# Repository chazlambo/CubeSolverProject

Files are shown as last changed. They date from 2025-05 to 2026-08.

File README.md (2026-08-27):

# CubeSolver

A self-contained Rubik's Cube solving robot: six stepper-driven faces, two servo
grippers on a moving ring, eighteen color sensors, an on-board Kociemba
two-phase solver, and a 320×240 display. Scan, solve, execute — no PC involved.

Everything here is one person's design: mechanical (SolidWorks), electrical
(KiCad), and firmware (Teensy 4.1).

---

## Status

**Working:** full autonomous scan → solve → execute cycle, driven from the
panel menu: the five Modes (Scramble Solve, Idle, Demo, Step Solve, Patterns),
on-panel tuning with defaults in source and overrides in EEPROM, a hardware jog
page, live sensor diagnostics, an EEPROM fault log and lifetime stats. The
display stays live during scan and solve, the abort chord works throughout,
encoder faults are detected and handled, a scan is validated piece-by-piece
with automatic repair, and color classification carries a per-sensor
confidence.

**Known unfinished:**
- `VirtualCube::rebuildFromCubeArray()` — still labeled `UNFINISHED NEEDS
  DEBUGGING` in its header, but the body is live and the firmware now relies
  on it (Cube State and pattern completion refresh the color array through
  it). The stale part is the label, not the code; it has no rollback on
  failure, which no current caller needs.
- Color sensor board 2, sensor 2 has a **dead green channel** — it reads exactly
  `0` for all six sticker colors in every archived calibration run. The firmware
  now detects this (`ColorSensor::checkSensorHealth`) but it is a hardware fault.
- Face steppers run without an acceleration ramp (`MultiStepper` is constant
  speed by design). Left as-is deliberately — a ramp would slow the solve.

---

## Which sketch do I flash?

**`Code/Main Code/CubeSolver/CubeSolver.ino`** — that's the program.

Everything under `Code/Test Code/` is bring-up and calibration tooling. The ones
still worth keeping:

| Sketch | Purpose |
|---|---|
| `Test Code/Bench_Tune` | Headless Serial protocol for scripted tuning: moves, parameters, every encoder before/after each move. Driven by `Code/tools/bench.py` |
| `Test Code/Actuator_Test` | Serial menu for manual moves and jam-recovery testing |
| `Test Code/Test_Motor_Calibrate` | Motor encoder calibration (also Settings → Calibration → Motor Positions) |
| `Test Code/Test_Color_Calibrate` | Color calibration (also Settings → Calibration → Color Sensors) |
| `Test Code/I2C_Search` | Bus scanner — genuinely useful on a five-mux rig |
| `Test Code/Test_Menu` | Menu, wheel and panel bench test — see below |

**`Test Code/Test_Menu`** drives the same `CubeMenu` and `CubeDisplay` the
firmware does, so anything that feels wrong there feels wrong in the firmware.
It runs no scan, solve or calibration. It does move real hardware from three
places: **Load** / **Eject**, the **Actuators** page (every servo and ring
position, each face motor and both whole-cube rotations, one part at a time),
and Diagnostics → Tuning → Servos, which drives a horn to each value as you
dial it. Everything under `Screens` is drawing only.

It also carries a `Screens` submenu that draws each operation screen (scan step
rows, calibration color chips, the solve progress bar, the error look) from
canned data, so the panel can be judged and photographed in seconds instead of
by running a 40-second scan to check one label. `Input Report` is a live
readout of the wheel count and every button — the fastest way to spot a flaky
encoder or a dead button.

It runs in the simulator too, with no machine at all:

```sh
cmake -S Code/sim -B Code/sim/build-test -DSIM_SKETCH=Test_Menu
cmake --build Code/sim/build-test -j && ./Code/sim/build-test/cubesim
```

`Test Code/_Archive/` does not compile against the current tree (it includes a
`Cube.h` that no longer exists). Git history is the archive.

---

## Build

**Board:** Teensy 4.1. Not a 4.0 — the solver's lookup tables alone are 4.14 MiB,
which is 214% of a 4.0's flash, and pins 40/41 don't exist on a 4.0.

**Toolchain:** Arduino IDE + Teensyduino.

> **TODO:** record the exact Arduino IDE and Teensyduino versions you build with,
> plus CPU speed and USB type from the Tools menu.

**Sketchbook layout — this is the non-obvious step.** `Code/libraries/` is an
Arduino *sketchbook libraries* folder, and the build must compile the repo's
copy, not a stale one. Two working setups:

1. **Point the sketchbook at the repo:** set Arduino's sketchbook location to
   the `Code/` directory (File → Preferences → Sketchbook location). Then
   `#include <CubeSystem.h>` and `#include <kociemba.h>` resolve, and
   `lv_conf.h` is found automatically.
2. **Link from the default sketchbook** (what this machine actually does —
   the sketchbook stays at `Documents/Arduino` so Library Manager installs
   land in the usual place):
   - `Documents/Arduino/libraries/CubeSolver` → symlink to
     `Code/libraries/CubeSolver`
   - `Documents/Arduino/libraries/kociemba` → junction to
     `Code/libraries/kociemba`
   - `Documents/Arduino/libraries/lv_conf.h` → a one-line forwarder header
     that does `#include "../../Projects/Cube_Solver/Code/libraries/lv_conf.h"`

Either way, do **not** copy the libraries into the sketchbook — you'll edit
the repo and build a stale copy. And never place an `lv_conf.h` inside the
`lvgl` library folder itself: if lvgl's own directory ever lands on the
include path, `__has_include("lv_conf.h")` silently builds the whole project
against that copy instead of the repo's.

### Dependencies

None of these are vendored except Kociemba. Install via Library Manager unless
noted.

| Library | Source | Notes |
|---|---|---|
| AccelStepper | Library Manager / airspayce.com | GPL-2.0 |
| MultiStepper | ships inside AccelStepper | constant-speed by design |
| PWMServo | bundled with Teensyduino | Teensy-only; **not** the stock `Servo` |
| TCA9548 | RobTillaart/TCA9548 | I²C multiplexer |
| veml6040 | ThingPulse/VEML6040 | color sensors |
| RunningMedian | RobTillaart/RunningMedian | scan filtering |
| Adafruit_seesaw | Adafruit | ANO scroll-wheel breakout |
| ILI9341_T4 | vindar/ILI9341_T4 (GitHub) | Teensy-4-specific DMA driver |
| LVGL | lvgl/lvgl | **v9.x** — the code uses v9-only APIs |
| EEPROM / Wire | Teensyduino core | two I²C buses used |
| SPI | Teensyduino core | pulled in transitively by ILI9341_T4, not included directly |
| kociemba | **vendored** at `Code/libraries/kociemba/` | from vindar/kociemba |

> **TODO:** pin the versions you actually build against, especially LVGL — the
> code uses `lv_display_create` / `lv_tick_set_cb`, which are v9-only.

### Menu theme assets

The menu's look is generated, not hand-drawn. `docs/theme/` holds the design as
two HTML files, and `Code/tools/bake_theme.py` rasterizes *those same files*
through headless Chrome at the panel's native 320x240, then packs the result
into LVGL C arrays under `Code/libraries/CubeSolver/utility/`:

```sh
python3 Code/tools/bake_theme.py              # images + fonts (needs network)
python3 Code/tools/bake_theme.py --no-fonts   # images only
```

The generated files **are committed**, so a normal build needs none of this —
run it only after changing the design. It needs `google-chrome`, `python3-pil`,
and `npx` for the font conversion.

Two things about those assets are load-bearing and easy to undo by accident:

- **They live in `utility/`.** `Code/libraries/CubeSolver` has no
  `library.properties`, so the Arduino IDE treats it as a 1.0-format library and
  compiles only the library root and `utility/`. Assets moved to a prettier
  subdirectory are silently not compiled, and the sketch fails to link.
- **The recolorable masks are RGB565A8, not A8.** LVGL reads an uncompressed
  RGB565A8 straight out of flash, but copies every alpha-only image into RAM
  first. The frame band alone is 49 KB — bigger than the 32 KB pool of the
  time, and most of today's 64 KB — so as A8 it fails to allocate, and with
  `LV_USE_LOG` at 0 it fails *silently*, drawing nothing at all. This costs
  about 220 KB of flash and is worth it.

Total asset cost: **~565 KB of flash**, against the ~3.3 MB left after the
solver's own 4.14 MiB of lookup tables. RAM is unchanged.

### lv_conf.h

`Code/libraries/lv_conf.h` is **required** and its settings are not defaults.
`LV_COLOR_DEPTH 16` must match what ILI9341_T4 expects; a mismatch does not fail
to build, it renders wrong colors and looks like a hardware fault. See the
comments in that file for the load-bearing settings.

**`LV_MEM_SIZE` is 64 KB, and running out of it hangs the machine.**
`LV_USE_ASSERT_MALLOC` is 1 and LVGL's default assert handler is `while(1);`, so
an exhausted pool is not a degraded UI — it is a halt, with no message, because
`LV_USE_LOG` is 0. It started at 32 KB, which the themed menu alone came within
~1 KB of; the operation screens took the peak to ~27 KB and the firmware hung
at boot with no output at all, so it went to 48 KB. The Sensor Test chips then
took the widget set to 35 KB and tripped the boot warning below, so it went to
64 KB. Every raise was set against a measurement, not a guess.

Two things watch this now: `CubeDisplay::begin()` prints the pool usage over
Serial once every widget exists, and warns below 8 KB free; and `M` in the
desktop simulator prints it live. Check the boot line before assuming a new
screen is free.

---

## Wiring

Verified against the `TEENSY_4.1` footprint's pad-to-net mapping in
`Circuitry/KiCad/Cube Solver/Motherboard/Motherboard.kicad_pcb`.
`Code/libraries/CubeSolver/CubeHardwareConfig.cpp` is the single source of truth
in firmware.

| Pin | Signal | Pin | Signal |
|---:|---|---:|---|
| 0 / 1 | U step / dir | 18 / 19 | **I²C0** SDA / SCL |
| 2 / 3 | R step / dir | 22 / 23 | Bottom / Top servo |
| 4 / 5 | F step / dir | 24 / 25 | B step / dir |
| 6 / 7 | D step / dir | 26 | Stepper enable (all 7) |
| 8 / 9 | L step / dir | 28 / 29 | Ring step / dir |
| 10 | Display DC | 30 | Encoder mux /RESET |
| 11 / 12 | Display MOSI / MISO | 32 | Power sense |
| 13 | Display SCK (+ onboard LED) | 40 / 41 | Color LED 2 / 1 |
| 14 / 15 | Display CS / RESET | 16 / 17 | **I²C1** SCL / SDA — see note |

**I²C addresses**

| Addr | Device | Bus |
|---|---|---|
| `0x70` | TCA9548 — encoder mux (7 AS5600 behind it) | Wire |
| `0x74`–`0x75` | TCA9548 ×2 — color board 1 | Wire |
| `0x76`–`0x77` | TCA9548 ×2 — color board 2 | Wire |
| `0x36` | AS5600 magnetic encoder ×7 | Wire (behind mux) |
| `0x10` | VEML6040 ×18 | Wire (behind muxes) |
| `0x49` | Adafruit seesaw (ANO wheel) | **Wire1** |

No pin or address conflicts.

### ⚠ Known board/firmware divergence

The firmware puts the scroll wheel on **Wire1 (pins 16/17)**, but Motherboard
Rev A routes connector J17 to **Wire0 (pins 18/19)**, and Teensy pads 16/17 are
marked unconnected. Since the machine works, there must be a bodge wire.

> **TODO:** confirm the bodge and either roll it into a Rev B or note it on the
> board. Right now this exists only in the hardware and in your head.

- **The color scanner is mounted rotated 90° from its original layout.** It
  was turned in CAD to make the assembly fit, which changed which faces each
  scan pass reads — from `[L,B] [U,F] [D,R]` to
  `[Back,Right] [Left,Down] [Up,Front]` — and **no firmware changed**, because
  `scanCube()` identifies each face from its own centre color rather than
  assuming which one it is looking at. What the design does rely on is the two
  sensors' position *relative to each other*, and rotating the whole assembly
  preserves that. Moving one sensor relative to the other would not, and would
  break `left1`/`left2` in `scanCube()`.

  The only thing tracking the physical order is `kScanPassFaces` in
  `CubeOpShape.cpp`, which fills the panel's face row during a scan. Rotate the
  scanner again and that table is the one thing to update.

Two other things worth knowing:
- **Pin 10 must be the display DC.** ILI9341_T4 drives DC through the SPI
  peripheral's chip-select logic during DMA, so it has to be a hardware CS pin —
  on Teensy 4.1 SPI0 that's 10, 36 or 37. A plain GPIO fails confusingly.
- Pins 24/25 are Teensy's `Wire2`, consumed by the B stepper. There is **no third
  I²C bus available** without moving that motor.

---

## First run

Order matters — the solver needs both calibrations, and color calibration needs
motors that already home correctly.

### 1. Motor encoder calibration

Menu → **Settings → Calibration → Motor Positions**, or flash
`Test Code/Test_Motor_Calibrate`.

Records four encoder positions per motor, one per quarter turn, into EEPROM.

> **TODO:** describe the physical setup — how the fingers should be positioned
> relative to the cube before starting, what a good result looks like, and when
> this needs redoing after a mechanical change.

### 2. Color calibration

Menu → **Settings → Calibration → Color Sensors**, or flash
`Test Code/Test_Color_Calibrate`.

Needs a **solved** cube. Steps through orientations recording a reference RGBW
per color per sensor, plus an "empty chamber" reference.

The firmware now derives a per-sensor decision threshold from this data
(`ColorSensor::computeSeparations`) rather than using one global tolerance, so a
bad calibration degrades classification measurably. Check the health report.

> **TODO:** describe ambient lighting conditions, whether the lid should be on,
> and how to tell a good calibration from a marginal one.

### 3. Servo endpoints

Menu → **Settings → Calibration → Servo Positions**. Rows preview live as the
wheel turns, behind a red confirm; values persist in the tuning EEPROM block.

The compiled defaults live in the shared parameter table
(`Code/libraries/CubeSolver/CubeTuneTable.cpp`), not in
`CubeHardwareConfig.cpp` — the `topExtPos` / `botExtPos` globals there are read
once at servo construction and then overridden at boot by the table, so editing
them no longer changes the machine.

> **TODO:** record how the defaults were determined and how to retune after
> changing a servo horn or linkage.

---

## Operating

1. Power on. The machine homes its motors if calibrated.
2. Turn the wheel to **Load & Scan Cube**, press SELECT.
3. Insert a scrambled cube, press SELECT. It scans (~25–40 s) and the main
   menu becomes **Cube Ready**.
4. Select **Solve**, press SELECT. It computes and reports the move count.
5. Press SELECT to execute (LEFT cancels and leaves the cube as it is).

**Abort:** hold SELECT and LEFT together for 1.5 s during a scan or solve. The
machine stops at the next mechanically safe point, releases the cube, and
returns to the menu.

**On any error that can leave the machine holding the cube, it is released
automatically** — the solve paths and the abort paths all route through
`safeStop()`. Scan-time color and build errors do not, because at those points
the ring and both servos are already retracted.

### Error codes

| Range | Meaning |
|---|---|
| Scan 1–3 | A sensor could not identify a face, or two faces read the same |
| Scan 1X/2X | Sensor 1/2's face was rejected when set on the virtual cube |
| Scan 3X | Could not determine orientation |
| Scan 41 | Fewer than six distinct faces set — a duplicate-centre misread |
| Scan 42-47 | Wrong number of some color (not nine of each) |
| Scan 5X | Could not build the cube array |
| Scan 60 | Physically impossible cube, auto-repair failed → rescan |
| Scan 70 | Aborted by user |
| Scan 80 / 81 | Reorientation move ROTX / ROTZ failed (encoder fault) |
| Scan 90 | A color sensor board failed to initialise at boot |
| Scan 91 | Motors failed to home before the first clamp (jam / encoder fault) |
| Cal 82 | A calibration reorientation move failed |
| Solve 11 | Cube not scanned yet |
| Solve 12 | No solution — illegal cube or solver timeout |
| Solve 13 | Centres not canonical → **orientation** was misread |
| Solve 14 | Impossible piece → a **color** was misread → rescan |
| Solve 15 | Solution longer than the move buffer |
| Exec 105 / 125 | Aborted by the user (between moves / inside a move) |
| Exec 1XX | A move failed; cube released and virtual state invalidated |
| Move 3 / 21 / 22 / 24 / 25 | Raw move (Modes, jog): invalid token / motors not calibrated / jam or align timeout / encoder unreadable / aborted |
| Move 1X | Virtual move failed — rescan |
| Cal 8 | Color calibration failed to save — machine is **not** calibrated |
| Cal 9 | Color calibration aborted; EEPROM left untouched |

The raw-move codes appear on the panel when a scramble, idle turn, pattern
fold or jogged move fails, and in the Fault Log under the Mode and Jog
sources.

Code 14 and 60 both mean "the cube I think I have cannot exist" — the fix is a
rescan, not a retry.

**Code 13 is effectively unreachable, by design.** `buildCubeArray()` relabels
colors through the reported orientation, so the centres come out canonical
whatever that orientation was. A *misread* orientation therefore produces a
different but internally consistent cube that is legal, piece-valid and
solvable — the machine would execute ~20 moves in the wrong frame with no error
at any layer. The centre check is kept as cheap insurance against a corrupted
`cubeArray`; detecting an orientation misread needs a cross-check against
something outside the cube model and is **not currently implemented**.

---

## Repo layout

```
3D Models/      SolidWorks parts and assemblies, plus print-ready STLs
Circuitry/      KiCad projects: Motherboard, Motor Breakout, Color Sensor
Code/
  Main Code/CubeSolver/   <- THE PROGRAM
  Test Code/              bring-up and calibration sketches
  libraries/
    lv_conf.h             required LVGL config (see above)
    CubeSolver/           the machine's own code
    kociemba/             vendored solver (from vindar/kociemba)
```

`.gitignore` excludes regenerable KiCad output (auto-backup zips, footprint
caches, per-user project state) and SolidWorks lock files. `.gitattributes`
marks binary CAD/fab formats `-text` so git's heuristic can't CRLF-mangle them.

---

## Notes for future-you

- **The alignment step sign lives in one place.** `CubeSystem::kAlignStepSign`.
  Both closed-loop routines use `encError()`; if alignment ever drives away from
  target, flip that constant and nothing else.
- **Encoder reads can fail.** `MotorEncoder::scanChecked()` returns negative on
  I²C failure and every control path treats that as a fault, not a position.
  Never go back to raw `scan()` in a control loop.
- **`pumpDelay()` instead of `delay()`** anywhere that waits more than a few ms,
  so the display and abort keep working.
- **The panel is driven synchronously, on purpose.** `CUBE_DISPLAY_ASYNC_DMA`
  in `CubeDisplay.h` is 0: every LVGL flush is written straight to the glass
  and returns when it is on the wire. The driver's async DMA/differential mode
  (mode 1) is faster, but on this board it left the glass holding the previous
  frame in large chunks, or coloured snow, while the driver believed the new
  one had been sent — and because that mode only ever re-sends pixels it thinks
  changed, the damage stayed until something drew over it. The header comment
  has the history. `cubeDisplay.repaintAll()` re-sends every pixel; the sketch
  calls it at the end of boot and on every return to the menu. In mode 1 never
  use `tft->update(internal_fb)` for that: handed its own buffer the driver
  rotates it onto itself.
- **A white panel heals itself now.** On the same marginal wire, a corrupted
  byte during a heavy flush can land in the panel's command slot — `RAMWR`
  (0x2C) and `CASET` (0x2A) are each one flipped bit from `DISPOFF` (0x28) —
  and a panel that latches `DISPOFF`/`SLPIN`/`SWRESET` shows solid white,
  which no amount of pixel drawing repairs. `CubeDisplay::panelHealthTick()`
  (run from every `update()`) re-sends `DISPON`+`SLPOUT` each second and
  re-runs the full init when the self-diagnostic register reads wrong, so a
  white-out lasts about a second instead of until power-cycle. It prints
  `Display: panel lost its init (recovery #N)` on Serial; that count climbing
  while scrolling is the wire talking.
- Solve times: Kociemba runs from flash. `set_memory()` would be ~4× faster but
  the 479 KiB buffer doesn't fit alongside the display's ~200 KB of RAM2.

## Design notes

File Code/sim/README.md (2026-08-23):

# CubeSolver desktop menu simulator

Runs the **real firmware** on a PC, with the ILI9341 panel and the seesaw wheel
replaced by SDL. Layout, fonts, text wrapping, navigation and LVGL memory
behaviour are all faithful, because they are produced by the same code that
ships — there is no second copy of the menu to drift out of step.

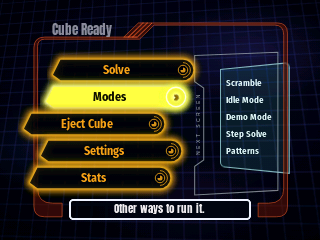
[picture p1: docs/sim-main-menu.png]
what it looks like


## Build and run

```sh
cmake -S Code/sim -B Code/sim/build
cmake --build Code/sim/build -j
./Code/sim/build/cubesim            # --scale 1..8, default 3
```

By default this builds the firmware sketch. `-DSIM_SKETCH=Test_Menu` builds
`Code/Test Code/Test_Menu` instead — the bench sketch for the wheel, the buttons
and the panel, including canned demos of every operation screen. Use a separate
build directory so the two do not fight over one CMake cache:

```sh
cmake -S Code/sim -B Code/sim/build-test -DSIM_SKETCH=Test_Menu
cmake --build Code/sim/build-test -j && ./Code/sim/build-test/cubesim
```

Needs `cmake`, a C++17 compiler, and network access on the first configure:
LVGL is fetched, not vendored, and so is SDL2 unless pkg-config finds a system
copy (`libsdl2-dev` on Debian/Ubuntu makes the configure faster, nothing more).

```sh
sudo apt install cmake build-essential libsdl2-dev   # optional on Linux
```

## Controls

**Machine controls** — these are the real machine's inputs:

| Key | Acts as |
|---|---|
| up / down arrow, mouse wheel | turning the wheel |
| `W` / `S` | the discrete UP / DOWN buttons |
| `Return`, `Space` | SELECT |
| left arrow, `Backspace` | LEFT (back) |
| right arrow | RIGHT (enters, same as the firmware) |
| `Return` + left arrow, held 1.5 s | abort the running operation |

**Simulator controls** — these do not exist on the machine:

| Key | Effect |
|---|---|
| `F` | arm a fault; the next operation fails |
| `C` | toggle whether a cube is loaded and scanned (flips the main menu) |
| `K` | toggle the calibration flags |
| `M` | print the LVGL heap report to the console |
| `P` | screenshot to `sim-shot-NN.bmp` |
| `Esc`, close window | quit |

## What is real and what is not

**Real, compiled unmodified from `Code/libraries/CubeSolver`:** the sketch
itself (`CubeSolver.ino`), `CubeMenu`, `CubeDisplay`, `RotaryEncoder`,
`CubePump`, `CubeServo`, `CubeMotors`, `ColorSensor`, `MotorEncoder`,
`VirtualCube`, the baked theme assets in `utility/`, and the repo's own
`lv_conf.h` — including its `LV_MEM_SIZE`, so LVGL pool pressure shows up
here rather than on the bench.

That last point is not theoretical. The menu theme's frame band was originally
baked as an A8 mask, which LVGL copies into RAM rather than reading from flash;
at 49 KB it did not fit the pool, and because `LV_USE_LOG` is 0 it failed by
silently drawing nothing. `M` prints the heap so that class of bug is visible
here instead of on the bench. The pool is 64 KB (`LV_MEM_SIZE`);
`CubeDisplay::begin()` prints its usage at boot and warns below 8 KB free, and
note that exhausting it halts the firmware in a `while(1)` rather than
degrading — which is exactly how it presents: a window that never draws.

**Real behaviour worth knowing about:**

- Start-up takes about ten seconds. Both servos sweep at 15 ms/degree through
  the real `CubeServo` code, exactly as the machine does. The first run is the
  slowest, because with no `sim-eeprom.bin` the servo state is unknown and
  `begin()` assumes worst-case travel.
- The abort chord is the firmware's own `pumpTick()`, copied rather than faked.
  Hold `Return` + left arrow during a scan and watch it unwind.
- `sim-eeprom.bin` persists calibration flags and servo positions between runs.
  Delete it to simulate a virgin board.

**Simulated:** `CubeSystemSim.cpp` replaces `CubeSystem.cpp` — the *only*
firmware file the simulator swaps out. Scan, solve, execute and calibration
report progress and consume a plausible amount of time (roughly a fifth of the
machine's, so menu work does not mean waiting out a 40-second scan), and can be
made to fail with `F`.

**Not simulated:** SPI refresh rate and tearing on the real panel, I2C timing
and bus contention, seesaw debounce, and actual cube solving — `kociemba` is
stubbed. The virtual cube's ready/not-ready state *is* real, which is what
drives the pre-scan vs post-scan main menu.

## Driving it from a script

Screenshots and regression walkthroughs work with `xdotool`, with three traps.
All three fail the same way — silently. Keys go nowhere and the run finishes
looking successful, so a walkthrough that captures no screenshots is far more
likely to be a driver problem than a firmware one. Check the shot count first.

```sh
./Code/sim/build/cubesim --scale 2 &
sleep 14                        # let the servo sweeps finish

# Trap 1: SDL creates more than one X window and only one of them takes
# keyboard focus. Do not guess which — try each and keep the one that sticks.
for W in $(xdotool search --name "CubeSolver menu simulator"); do
    xdotool windowactivate --sync "$W" 2>/dev/null; sleep 0.3
    [ "$(xdotool getwindowfocus)" = "$W" ] && WID=$W
done

# Trap 2: buttons are LEVEL-sampled every 25 ms by the firmware, so a press must
# be HELD. `xdotool key Return` is far too brief and is silently dropped.
#
# Trap 3: focus DRIFTS. Focusing once at the start is not enough — a few keys in,
# focus lands on some other window and the rest of the walkthrough types into it.
# Re-assert focus before every key; it costs a few ms and removes the whole class
# of "it worked yesterday" failures.
act()  { xdotool windowactivate --sync "$WID" 2>/dev/null; }
tap()  { act; xdotool key "$1"; sleep 0.7; }
hold() { act; xdotool keydown "$1"; sleep 0.16; xdotool keyup "$1"; sleep 1.0; }

hold Return                     # SELECT
tap p                           # screenshot (the wheel/encoder path IS
                                # event-driven, so brief keys work for it)
```

## Going further (Tier 2)

Swapping `CubeSystemSim.cpp` for the real `CubeSystem.cpp` would give genuine
scan → solve → execute against a real virtual cube, enough to develop Scramble,
Idle, Demo and Patterns entirely on a PC. Two things stand in the way:

1. `homeMotors()` and `alignMotorsInternal()` poll the AS5600 encoders in a
   loop, so `MotorEncoder`/`AccelStepper` need to model a motor converging on
   its target rather than returning a constant.
2. The real kociemba solver has to be added to the build. It is portable C++ and
   compiles on a host unmodified — `shim/kociemba.h` deliberately keeps the same
   signature as `Code/libraries/kociemba/kociemba.h` so this is a build-list
   change, not a code change.

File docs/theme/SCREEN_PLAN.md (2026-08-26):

# Screen plan — what the rest of the machine needs to look like

Every menu item that once landed on "Not implemented yet", designed before it
got written. As of firmware 1.0.0 every screen here is **BUILT**, machine side
included — the per-screen statuses say so. The point was never to lock anything
down; it is so that the tenth screen looks like it belongs with the first, and
so the shared pieces get built once instead of five slightly different times.

Read `UI_DESIGN.md` first — it covers the palette, the limits and the traps.
This file was about screens that did not exist yet; it stays as the record of
why each one looks the way it does.

---

## The rule everything here follows

**Bar art means "you can select this."**

The glowing bar with the socket and the cursor orb is the menu's vocabulary for
a choice. It was briefly reused to show scan progress, and the result read as a
screen full of buttons that did nothing — the shape promised an interaction that
was not there.

So: a bar is a thing you can pick. Status is chips, a progress bar, a table, or
text. Never a bar. When something is genuinely a list of choices — Patterns,
Parameters — bars are exactly right and should be used.

Second rule, and it has been rewritten since most of this file was: **the
frame color is where you are.** A branch of the menu tree is one color from the
row that opens it all the way out through the operation screens it leads to —
blue for the main line of work, red for Modes, green for Eject, yellow for the
whole Settings subtree, purple for Stats. A new screen does not pick a color;
it inherits its branch's.

It used to mean machine state — blue scanning, green solving, violet
calibrating — and several sections below still describe screens in those terms,
noted where they do. The two schemes fought over one band, because a menu
already recolors by selection, and wayfinding won. Only `Error` kept its old
meaning: **red, always, whatever branch it happened in.** `UI_DESIGN.md` §2 has
the full rule and the one other exception (Idle Mode's decorative cycle).

### The Settings subtree

Restructured with the color change, since one branch of one color also wants to
be one branch of one shape:

```
   Settings
     Diagnostics     read the machine    Hardware Test, Sensor Test,
                                         Cube State, Fault Log
     Calibration     teach the machine   Status, Color Sensors,
                                         Motor Positions, Servo Positions
     Parameters      change the machine  the six tuning sections
     About
```

Diagnostics above Calibration because looking comes before altering, and
Parameters promoted out of Diagnostics to sit beside Calibration because it
WRITES — filing it under a menu named for reading was always a lie about it.
Every screen under Settings is yellow. That does cost the local distinction
Settings used to draw between Diagnostics (purple) and Calibration (violet);
the title line still says which, and one branch of one color is the trade.

---

## Vocabulary we have

| Piece | Call | Says |
|---|---|---|
| Frame color | `opScreen(kind, …)` then `setOpTheme()` | which branch you are in |
| Title | `showOperation(…, title, …)` | where you are |
| Headline / sub-line | `showOperation(…, headline)` / `setStatus()` | what it is doing now |
| Status table | `setOpLines()`, `"Label\tValue"` | facts, up to 7 rows (`kOpLines`) |
| Face row | `setOpFaces()` | the six faces, filled with the color actually read |
| Chip rows | `setOpChips()` | a set being collected, two rows |
| Progress bar | `setOpProgress()` | how far through a countable job |
| Dial | `setOpDial()` | a setting you are steering, and where it sits in its range |
| Hint box | `showOperation(…, hint)` | what button to press |
| Preview pane | menu only | what is behind this item |

## Vocabulary added while building

Where each of the later pieces lives:

| Piece | Call | Built for |
|---|---|---|
| Cube net | `setOpCubeNet()` | Cube State, scan review, Patterns, the two Solve thinking screens |
| Chip row | `setOpChipRow()` / `setOpFaces()` | scan faces, calibration, the jog strip |
| Move ribbon | `setOpRibbon()` | Step Solve |
| Row status marks | `setOpLines(..., marks)` | the jog cursor; Sensor Test uses it too |
| Frame recolor | `setOpTheme()` | the branch color, and Idle Mode's cycle |

Two more pieces came with the machine side:

1. **Scrolling status list**, for Fault Log. More than a page of rows
   (`kOpLines`, seven) with a position readout in the hint bar rather than a
   scrollbar the theme has no art for.
2. **Value editor**, for Parameters and Servo Positions. The Actuators
   page's enter-pick-send on a gripper proved the interaction; the editor adds
   a NUMBER rather than three named positions, with the step size a column of
   the shared parameter table.

### On the cube net — built, and how

`setOpCubeNet(facelets)` takes 54 color letters in the standard order and draws
the unfolded cross. `VirtualCube::getColorArray()` returns exactly that.

It is **not** LVGL primitives and **not** `lv_canvas`. It writes RGB565A8 into a
plain static buffer and hands that to an `lv_image`. Three reasons, all of which
apply to the next thing like it:

- 54 stickers as objects would be most of the pool for one screen.
- The buffer (39 KB at 10 px stickers) is several times the whole LVGL pool, so
  it must be a static array, not an `LV_MEM` allocation. Teensy RAM has room;
  the pool does not.
- LVGL reads an uncompressed variable-source image **straight out of the buffer
  without caching it** (`use_directly` in `lv_bin_decoder`). So redrawing is
  "rewrite the bytes, call `lv_obj_invalidate()`" — no reallocation, no cache
  invalidation dance.

Gaps between stickers are alpha 0, so the net sits on the themed backdrop rather
than on a grey slab. A facelet that is not a known color is drawn as a hollow
outline, so a bad sticker reads as wrong rather than as missing.

**Still missing:** per-face rotation for a *raw* scan. Cube State falls back to
showing the last scan when nothing was built, but each face is laid out as its
sensor saw it — `setOrientation()` resolves that only when the cube is built. A
stray sticker is visible; where it sits within its face may be turned. The
screen says "last scan, not built" rather than pretending otherwise.

```
        ┌──┬──┬──┐
        │  U     │            standard unfolded cross:
        ├──┼──┼──┼──┬──┬──┐   4 faces wide, 3 tall
        │  L  │  F  │  R  │  B     at 10 px/sticker -> 132 x 99
        ├──┼──┼──┼──┴──┴──┘   centred, with the sub-line below it
        │  D     │
        └──┴──┴──┘
```

---

## Screen by screen

Sketches are the ~240x150 content area inside the frame. The title sits top-left
and the hint box along the bottom on every one of them.

### Solve, the thinking half — top level — **BUILT**

The two screens between pressing Solve and the machine moving. Both are the
same picture: the net of the cube *as it stands*, drawn by `setOpCubeNet()`
from `VirtualCube::getColorArray()`. One function draws both — `drawSolveNet()`
in the sketch — because they ask the operator the same question, "is this the
cube you loaded", and only the line under the net changes.

```
        [ the unfolded net, y=60..150 ]
           Finding solution...                <- sub-line, under the net
                                              <- no hint: nothing is polled
```
```
        [ the same net ]
         Solution found in 21 moves           <- Cube.solutionLength, not a recount
      SELECT to solve, LEFT to cancel         <- hint box
```

**No headline on either**, and that is structural rather than taste: the net
occupies y=60..150 and `showOperation()` puts the headline at 58, so a screen
carrying both draws one through the other. `setOpCubeNet()` moves the sub-line
below the net for exactly this reason.

The first screen has **no hint** because `solveVirtual()` blocks *without*
pumping — nothing is polled while it is up, so an abort line would advertise a
gesture the machine cannot hear.

The first screen is painted by the Solve action but *flushed* by the `Solving`
state, which pumps one refresh period (`pumpDelay(40)`) before the search
blocks. A single `displayUpdate()` only marks widgets dirty; LVGL repaints when
its 33 ms timer comes due, and without the pump the panel stayed on the menu
for the whole compute — Solve read as a press that had not registered.

The second is `AppState::SolveConfirm`, and its whole value is that nothing has
started yet: no gripper driven, no solve timer, no stats touched. LEFT is
therefore free — it returns to the menu leaving the cube exactly as it stood
(clamped, in the usual case, which is where the scan and the previous solve
leave it) and leaving no half-started solve behind. SELECT falls through to
`Loading`.

**Only say the machine is clamping when it is.** `Loading` clamps *only* if
`cubeIsClamped()` says it is not already, and the "Clamping the cube" screen now
lives inside that branch. It used to be painted unconditionally on the way in
from `Solving`, which claimed a clamp on the common path where nothing moved.

The whole run — both of these, the clamp if there is one, the moves, the display
spin — wears the Solve row's **blue**, by the ordinary `s_opTheme` mechanism
(§ "The rule everything here follows"). Nothing on the path names a colour; the
`Op::Done` on the display spin is a label only, since `opScreen()` repaints the
branch colour over the kind's fallback. A failure leaves through `fail()` and is
red, as everywhere.

### Solve, the display spin — top level — **BUILT**

How a plain Solve ends. Not a straight release any more: the machine lets go of
the ring and the top servo, keeps the cube up on the bottom gripper, and turns
it slowly on the spot — one revolution about every eight seconds — while the
result stands on the screen. With nothing else engaged the D motor turns the
WHOLE cube rather than a face, which is why the model is never told about it.

```
                Solved!                     <- headline
           21 moves in 4.62 s               <- sub-line, the shared formatter
      SELECT clamps the cube and finishes   <- hint box
```

Reuses everything; needed nothing new. The interaction is the one novel part:
SELECT (or LEFT) finishes the revolution so the cube is square, clamps it again
bottom -> ring -> top, and returns to the menu — which leaves the machine
holding the cube, so the next Solve skips its own clamp.

**Modes do not end here.** They still finish through `Unloading`: Demo loops and
would stall on a screen that waits for a press, and Step Solve is already
human-paced. Making it universal is a one-line change, recorded in the sketch
above `drawSolveDisplay()`.

Rehearsed in `Test_Menu` as `Screens > Operations > Solve Result` — the
"Solved!" screen the Scramble Solve demo already draws, minus the ribbon and
bar, plus a hint. The spin itself is the part no bench sketch can show, so the
demo is the still frame only.

### Eject — top level — **BUILT**

Was a screen that asked for a press: "take the cube out, then press SELECT". It
watches now. The machine releases the ring and the top servo, lifts the cube on
the bottom gripper — `unloadCubeKeepBottom()` then `botServoEject()`, straight
there, no dip into the bay first — and then leaves both color boards illuminated
and sweeps all eighteen sensors five times a second.

```
             Take the cube out              <- headline
     SELECT if the machine does not notice  <- hint box
```

The hint is the whole design of the screen. The cube can just be taken, so the
headline says only that; the button is named as a backstop, not as a step,
because promising a press the operator does not need is how the old screen was
wrong.

Detection is **tare, pick witnesses, watch for the fall**. Once the LEDs have
warmed, three `presenceSweep()`s of every sensor on both boards are averaged
into a per-sensor baseline — taken while the cube is definitely still there.
The sensors reading at least 50% of the brightest baseline are the *witnesses*:
at the eject height the cube's lowest row sits a couple of millimetres from the
top row of each board and bounces the LED straight back, while everything else
looks at the bay, so brightness alone sorts out which sensors can see the cube.
The cube is gone when more than half the witnesses have fallen to 40% of their
own baselines for four consecutive sweeps. No absolute brightness anywhere —
ambient light, LED output and sticker color all vary, and each baseline is
measured against the very sticker that is about to leave. A negative read is
an I2C fault and is never removal. A *fall* rather than "any change", because
a hand reaching in is also a change — it reflects the LED into the bay-facing
sensors a second before the cube leaves — but it cannot get between a sticker
and the sensor it sits 2 mm from. The debounce is there because a cube loosely
held can clear its witnesses while still resting on the platform.

Every ending — detected, SELECT, the 120 s give-up timeout, the abort chord —
goes through one `ejectFinish()`: LEDs off, bottom servo down, back to the
menu, where the root list reverting to its pre-scan form is the confirmation.
No "Cube ejected" acknowledgement screen, because that was the press being
removed.

**No sensor is chosen by hand.** The first version watched one sensor — first
the centre, then the bottom-middle — and stood through its timeout, because
which of the nine is physically uppermost is not knowable from this tree: the
`{UL, UM, UR, ...}` names in `CubeHardwareConfig.cpp` predate the 90° scanner
rotation the README describes. Sweeping all eighteen and letting the tare say
which ones see the cube removes the guess. The tare and the verdict go to
Serial (`Eject tare ...`, `Eject: cube gone ...`), which is where the 50%/40%
thresholds get confirmed on the bench; the timeout exists so a machine whose
sensors cannot see the cube at this height costs two minutes rather than forever.

Rehearsed in `Test_Menu` as `Screens > Operations > Eject Prompt` — the
prompt only. `Test_Menu`'s own root `Eject Cube` is an actuator exercise, not a
screen demo, and the watch itself needs the real color boards, so neither
rehearses the detection.

### Scramble Solve — Modes — **BUILT**

Two phases — scrambling, then solving — and the headline, sub-line and bar all
say which. **They no longer recolor the frame.** The frame is red throughout,
because red is Scramble Solve's place in the tree, and the frame answers "where
am I" rather than "which half is this". The as-built plan below was written
under the old rule and the color half of it is superseded.

```
              Scrambling                    <- headline, per phase
             Move 7/25   R'                 <- sub-line
        ▓▓▓▓▓▓▓▓▓░░░░░░░░░░░░░              <- progress bar
```

Reuses everything. Needed nothing new. Built first — it was the cheapest of
the Modes, and the phase-color idea it proved is the one that later lost to
wayfinding.

### Idle Mode — Modes — **BUILT**

The machine turning to look alive between visitors: a random quarter turn every
so often, waiting for someone to walk past.

```
              R'                     <- the last move, large
        Moves      12
        Every      10 s
              wheel sets the gap - SELECT solves
```

Three controls share one screen and none needs a mode of its own, because
there is no cursor here to move and nothing to enter:

| | |
|---|---|
| wheel | how long between moves, 1-60 s |
| SELECT | stop idling and solve it |
| LEFT | back, as everywhere |

The gap **clamps** rather than wrapping. A cursor may wrap because every item is
equivalent; rolling a one-second gap round to a minute because the wheel went
one detent too far is a different kind of surprise. Changing it also re-times
the pending move from now — shortening the gap and then waiting out the old one
reads as the setting not working.

The frame color advances with each MOVE rather than on a timer of its own. This
is the one sanctioned exception to frame-color-as-wayfinding: everywhere else
the band says which branch you are standing in, and here it cycles all six on
purpose. Tying it to the moves is what keeps it honest — a color change means
something happened, so the machine reads as alive from further away than the
move counter can be read. Idle Mode's other screens (the clamp, and the solve
SELECT hands off to) wear the mode's own yellow.

Idling **disorders the cube** — Step Solve must not then scramble a cube that
is already scrambled. The firmware derives that from the cube model itself
(`cubeIsSolved()`) rather than a flag, so the two cannot disagree.

### Demo Mode — Modes — **BUILT**

Scramble, solve, repeat, unattended. Both halves already existed — the phase
handling from Scramble Solve, the ribbon from Step Solve — so it is a loop
around them plus a run counter.

Four phases, because the machine has four. The colors this table used to name
are gone: Demo Mode is **blue** end to end, its row's color in the Modes menu.
A run scrambles and solves and scrambles again every few seconds, and
recoloring the halves would have said the machine kept changing job.

```
   Scrambling                     30 moves, ribbon + bar
   Computing the                  the handover: no ribbon, no bar
     solution
   Solving                        21 moves, ribbon + bar
   Solved!                        the result, briefly
```

The pause to compute is not padding. The real machine has to work out a solution
before it can run one, and a demo that jumped from the last scramble move
straight to the first solve move would be showing something the machine never
does. The handover happens THERE rather than at the first solve move, because
that is the moment it stops scrambling — and the ribbon and bar go, because
neither has anything true to say about a search that has not finished.

It shows the MOVES because the whole point of leaving it running is that it
should be worth watching. The scramble is its own list — thirty moves, no two in
a row on the same face, which is what a real scramble looks like and the reason
it reads differently from a solution.

### Step Solve — Modes — **BUILT**

Scrambles thirty moves first, then steps — but only if the cube is not already
scrambled. Idle Mode and a previous run both leave it disordered, and thirty
moves spent re-scrambling a scrambled cube would be a lie about what the machine
does.

Three phases: scrambling with the scramble ribbon running, computing, then the
step-through. **Purple** throughout — Step Solve's color in the Modes menu — and
not the red/yellow/green progression this originally specified; see the second
rule above. The compute phase must still CLEAR the ribbon and the progress bar:
left up, a finished ribbon and a full bar sit under the word "Solving" and read
as a solve that finished before it started. Both hide on a null/zero argument.

One move per press. This is what the **move ribbon** is for.

```
             Move 7 of 21

     R   U2   F'   ⟨ L ⟩   D   B2   R'      <- current in cursor yellow,
                                               past dimmed, future grey
```

Deliberately **plain text tokens, no boxes** — boxed tokens would drift back
toward looking like buttons. Color alone carries the cursor.

`setOpRibbon(moves, count, current)` centres the window on the current move and
shows about seven. Hint: "SELECT for next move".

### Patterns — Modes — **BUILT**

A *menu*, so bars are correct here — and the preview pane is the obvious home
for a small cube net of what each pattern produces. That is the pane doing
exactly what it was designed for.

```
   ╭─ Checkerboard ─╮        ┌──────┐
   ╰────────────────╯        │ net  │   <- preview pane, ~66x96,
   ╭─ Cube in Cube ─╮        │      │      net at 5 px/sticker
   ╰────────────────╯        └──────┘
   ...
```

**Prototyped** in `Test_Menu` (Screens > Patterns). `MenuItem::previewNet` holds
54 facelets and `setPreview()` draws them in the pane at 3 px stickers, sharing
one `drawNet()` with the full-size version so the two cannot disagree about what
a cube looks like.

Nine patterns now, split across two screens because five rows is the limit:
Checkerboard, Cube in Cube, Six Spot and Superflip plus a **More Patterns**
row leading to Cube^3, Anaconda, Python, Tetris and Twister (sequences from
ruwix.com). Each screen's rows index the shared `kPattern*` tables from its
own base — table order is screen order, first screen then second.

The states are computed by applying each well-known sequence to a solved
cube and checked for nine of every color — a preview that is not a real cube
would hide exactly the bugs this screen is for.

The machine side — running the moves — is built now too. The fold refuses a
cube that is not solved, because the preview is a promise about the result.

### Cube State — Diagnostics — **BUILT**

The net plus a color count. Nine of each is the cheapest check that the stored
state is a cube at all, and unlike "invalid" it says *which* color was misread.

It doubles as the **scan review**: with nothing built but a scan recorded, it
shows the raw readings instead of an empty screen — which is the case where
somebody most wants to look. See the caveat above.

**And it turns.** With a model built, the wheel points at a face and UP/DOWN
turn it, with the net redrawing after each move. The turn is applied to the
**model only** — no motor, no servo — which is the opposite half of the trade
`jogTurn()` makes on the Hardware Test page: that page moves the machine and
therefore cannot keep the model, and this one keeps the model and therefore
must not move the machine. Same desync, opposite ends.

The screen says so in capitals under the net, next to the `< U >` selector,
because the whole risk of the page is an operator believing the machine just
moved.

A model left turned would desync just as badly the other way — Solve would run
against a state the machine is not holding — so the page does not leave it
turned. Every move goes on a 60-entry trail (a turn that undoes the previous
one pops instead of pushing, so forward-and-back costs no depth) and **every
exit replays it backwards inverted**. A scan survives a visit here.

The raw-scan form stays read-only: `VirtualCube::executeMove()` refuses a cube
that is not ready, and the per-face rotation is unresolved anyway, so a turn
would shuffle stickers inside a frame that does not mean anything yet.

Still worth adding: mark the low-confidence stickers. `scanAlt` and `scanConf`
already record the runner-up color and the confidence for every sticker, so the
data is there — a hollow or outlined sticker for "the classifier was unsure
about this one" would turn this from *what it read* into *what to distrust*.

### Fault Log — Diagnostics — **BUILT**

A list nobody selects from, so status rows rather than bars.

```
        12:04   Solve stopped      122
        11:58   Scan failed         60
        11:51   Aborted             25
        ...
```

Seven rows at a time — the whole of `kOpLines` — wheel scrolls, and the
position goes in the hint box — "8-14 of 24" — rather than inventing a
scrollbar the theme has no art for.

### Hardware Test — Diagnostics — **BUILT**

**Not a self-test.** It is manual control: drive each actuator to each position,
by hand, one at a time. The panel version of `Test Code/Actuator_Test`, which is
a numbered list over Serial. It is where you go to answer "does that servo
actually reach retract", and where you drive one part at a time to show the
machine off.

It started as a menu of every action, and that was wrong: nine entries across
three screens for the grippers alone, twelve more for the faces, all clicked
through one at a time — when what you want is to pick a thing and nudge it while
you watch it move.

So the two busy pages are **direct manipulation**, not menus. They can be,
because the wheel and the UP/DOWN BUTTONS are separate inputs on this encoder.
A menu collapses them into one meaning; a jog page gives them two:

```
    wheel        choose which part
    UP / DOWN    move that part
    LEFT         back, exactly as everywhere else
```

**One page, no submenu at all.** Twelve things on one wheel — three grippers,
the cube button, six face motors, two whole-cube rotations — and it wraps.

```
   Top servo                  < Extend >     <- entered: the candidate
   Bottom servo                       ?
   Ring                          Middle
   Eject cube                                <- named for what it will DO
   [U] [R] [F] [D] [L] [B] [RotX] [RotZ]
```

Load and eject are ONE row, because the cube is either in the machine or it is
not. It is named for what pressing it will do, so there is nothing to read twice.

Keeping them together is not only tidiness. **A face motor cannot turn until the
grippers are clear**, so seeing where the grippers are WHILE jogging a face is
the difference between a considered press and a jam.

**Two levels everywhere: scroll to a thing, SELECT to enter it, LEFT to leave.**
Entering something used to turn the frame yellow. The frame is Settings' yellow
throughout now — it says where you are, not what is armed — so the hint line and
the row mark carry that instead. Both already changed with the state.

What the wheel then does depends on what you entered, and that difference is the
whole design:

- A **gripper is a position**. The wheel picks one, SELECT sends it, and nothing
  moves until you say so.
- A **motor is a thing you turn**. Once you have taken the wheel, every detent
  IS a turn — which is what a jog wheel should feel like, and it means watching
  a motor through several turns costs no button presses at all.

The cursor is a **marked row**, not a bar:
they are a readout you are steering, and bar art would promise a selection that
is not what is happening. Position reads "?" until it is known — the servos
remember across a reset but nothing exposes it, and guessing is worse than
admitting it. Load and eject both end at a known state, so those rows can say so
rather than falling back to "?".

Everything that turns is one **chip strip**, faces and whole-cube rotations
together, because they are the same gesture. Eight of anything does not fit five
bars; as chips it fits with room. The strip sizes its chips to the count so it
always clears the frame band, and six still comes out at exactly the width the
scan screen has always used.

The hint bar carries what the buttons do and changes with what is selected —
there is no one sentence true of both a servo and a face motor.

Built in `Test_Menu` under Actuators first, and now ported into the firmware's
Diagnostics menu as **Hardware Test**; the bench page stays as the rehearsal —
change both.

### Color Sensors — Diagnostics — **BUILT**

Two health rows and eighteen live chips, nine per board. The chips ARE the
readout: eighteen color names would take longer to read than the cube takes to
scan, and the thing you are hunting — one sensor disagreeing with its
neighbours — shows up instantly as a chip of the wrong color.

```
   Board 1              9/9 healthy, sep 165     <- green
   Board 2              8/9 healthy, sep 3       <- red
   [][][][][][][][][]                            <- board 1, live
    1  2  3  4  5  6  7  8  9
   [][][][][][][][][]                            <- board 2
```

The wheel moves a cursor across all eighteen and **SELECT drills into one**:

```
   Board 1  Sensor 4
   Red                              902
   Green                            252
   Blue                             222
   White                           1376
   Reads as                       Orange     <- green, or red for "unusable"
```

That second screen is for "why did it call that sticker orange". The
classification is a judgement made from four numbers, and until you can see them
the answer is a guess.

The demo draws board 2 sensor 2 as unusable, because on this machine it is (a
dead green channel; see the README). A diagnostic that only ever shows healthy
hardware is not a diagnostic.

On hardware the values come from `colorSensorN.currentRGBW` right after a
`scanSingle()` — `getScanValRow()` holds the last full-face scan, which this
screen would show as stale data. Wants a 3x3 grid per board eventually, to
match the physical face.

### Motor Sensors — Diagnostics — **BUILT**

Seven encoders, seven numbers — six faces and the ring, raw 12-bit angles.

Nothing here is a picture, because an angle is not one. What you are checking is
whether a value moves when you turn a face, and whether any encoder is reporting
an I2C error instead of an angle. `MotorEncoder::scan()` returns the angle or a
negative error code, and showing the error rather than a plausible number is the
point of the screen.

The DIAL this page opens (SELECT on a face row) grew real moves later: there,
UP and DOWN run a full quarter turn — UP the plain move, DOWN the prime (U /
U' with U entered) — so one motor's encoder can be watched across repeated
aligned turns in each direction, which is the shape of a direction-dependent
fault. Deliberately on the dial and not on the list: on a list you are
navigating, a button that turns a motor fires on whatever row it lands on,
and entering the motor first is what says "this one, on purpose". Diagnostic
owner only — the CalFlow dial keeps UP/DOWN as single detents, because an
aligned move there would home a hand-squared face back to the old marks. See
`dialTurn()` in the sketch, mirrored in Test_Menu with canned encoder motion.

### Tuning — Calibration > Servo Positions and Settings > Parameters — **BUILT**

The one that needed a genuinely new interaction: the wheel changes a *value*,
not a cursor. Built as a settings list kept separate from `CubeMenu` rather than
bolted onto it — `CubeMenu` is navigation-only and host-testable, and value
editing is a different job.

Six sections, each a window onto one flat table:

| Section | Rows |
|---|---|
| Servos > Top Servo | extend, retract, sweep delay |
| Servos > Bottom Servo | extend, retract, partial, eject, sweep delay |
| Servos > Ring | retract, partial, middle, extend, speed, accel |
| Face Motors | step speed, step delay, rotate delay, servo delay |
| Alignment | tolerance, align timeout, home timeout, debug log |
| Color | scans averaged, integration, color tol, margin frac, distance frac, min separation |

Plus **Reset Defaults**, which clears the EEPROM stamp and re-applies every
compiled default — all six sections at once. One section at a time is done
from inside the section: UP or DOWN on its Apply row stages that page's
defaults as pending values, and Apply writes them.

#### Interaction

- Scroll to a row, SELECT to enter, wheel to change, SELECT to keep, LEFT to
  restore. The frame no longer changes on entry — it is Settings' yellow the
  whole time — so the hint line becomes the value's range instead.
- **Nothing is applied until the Apply row is pressed.** A parameter was one
  press and one detent away from being changed for good, and a machine that
  quietly kept the accident offered no route back to the number that worked.
  What is gated is the *commit*, never the preview: a servo endpoint is set by
  eye, so `previewRaw()` still runs on every detent exactly as before, and it
  is `set()` that waits. While a section is open the owners and EEPROM hold
  `parBase[]` and the wheel moves `parVal[]`; `set()` and `tuneSaveAll()` are
  reached from the Apply row and nowhere else.
- Changed rows carry a **leading star**, and the Apply row's value is the count
  ("3 changed"). The star is in the label column rather than being a `RowMark`
  because the cursor already owns the mark.
- A value that is **not the compiled default** is drawn in amber
  (`RowMark::Tuned`), so a page read cold says which numbers have been tuned
  without anything having to be pressed. Amber, not yellow: the cursor is
  already yellow. It follows the value shown, so a row wheeled back to its
  default stops being amber as it gets there; the star still says it is
  pending. On the cursor row the cursor wins, as it does over every mark.
- **UP or DOWN on the Apply row loads this page's defaults** — as pending
  values, through the same Apply gate, with no preview of the live rows (the
  parts move when Apply stores the values and the machine next uses them,
  exactly as after Reset Defaults). There is no row for it because Ring and
  Color plus Apply already fill all seven lines. The hint on the Apply row
  offers it whenever it would do something.
- LEFT with changes pending **asks, in red** — the same shape as Reset
  Defaults' confirm, and SELECT is the destructive answer there as it is
  everywhere else in this sketch. Discarding drives every previewed part back
  to its base value first: a live row has already moved the horn, so forgetting
  the number is only half of putting it back.
- A **toggle** flips in place. Entering an edit mode to choose between two
  values would be three presses to change one bit.
- A **gated** row shows a red confirm FIRST. That ordering is the whole point:
  gated rows preview as the wheel turns, so by the time you could confirm a
  value the horn has already been there. What is confirmed is "I am about to
  move this part", not "I accept this number".
- The **description** of the selected row lives in the sub-line, above the rows.
  It has to be set BEFORE `setOpLines()`, which reads it to decide where rows
  start — set afterwards, it lands on top of row one.

#### Traps this screen is built around

**Accessors, never the config globals.** `CubeServo` copies `topExtPos` at
construction and never reads it again, and the `CubeMotors` tunables were
private. An editor written the obvious way shows numbers changing and moves
nothing. Same trap, twice more: `ColorSensor::begin()` is the only caller of
`setConfiguration()`, so integration time needed
`ColorSensor::applyIntegrationTime()` to mean anything at runtime; and
`waitTime` is documented as "integration time * 2.5" but has always been
1.875x, so it is derived from the ratio the machine actually runs.

**One detent is one step, however fast the wheel spins.** A live row writes the
servo on every change and `previewRaw()` jumps rather than sweeps, so honouring
a burst of detents at once turns a nudge into a slam.

**Persist on the way out, not per detent.** `previewRaw()` deliberately skips
EEPROM. But skipping it entirely is worse than either: `CubeServo::begin()`
trusts the stored position to decide how far its first sweep travels, so a stale
one arms a full-travel slam on the next power-up. That write records where the
horn is *standing*, not what its endpoints are, which is why it is right on the
way out of an Apply and equally right on the way out of a discard.

**Angle brackets are ASCII.** The baked fonts carry 0x20-0x7F and a missing
glyph draws as an empty box in silence.

#### What is deliberately NOT here

- **Turn step** — steps per quarter turn is gearing, not preference. A wrong
  value does not make solves worse, it makes them impossible. `CubeMotors` has
  a getter and no setter, on purpose.
- **Wait time** — derived from integration time. Exposing both invites an
  inconsistent pair that misreads every sticker.
- **Saturation threshold, step size, stable required** — properties of the
  VEML6040 and of homing internals, not of this machine.
- **Abort hold time** — the SELECT+LEFT duration. It is a safety gesture, not a
  preference: too short and a solve aborts by accident, too long and the abort
  reads as broken. Nothing about it varies per machine.

#### Persistence

Defaults live in the table, overrides in EEPROM, via `CubeTuning` — a version
stamp plus a flat array of int32. Values are stored BY POSITION, so **reordering
or inserting a parameter must bump `CubeTuning::kVersion`**; without it the next
boot hands an alignment tolerance to a servo. The block is appended at the END
of `initializeEEPROMLayout()` and has to stay there: addresses are handed out
sequentially, so a block inserted higher shifts every one below it and silently
reinterprets an already-calibrated machine's motor and color data.

One behaviour change worth knowing: the bottom servo's partial and eject
positions are now **pinned** rather than derived from the extend position, since
boot applies every value whether it came from EEPROM or from the defaults.

### Motor Calibration — Calibration > Motor Positions — **BUILT**

Was one blocking call behind a "Finding home positions" screen. It is a flow
now, because of what `calibrateMotorRotations()` actually does: it turns every
face through four quarter turns and files the readings **relative to wherever
the motors were standing when it started**. A face left out of square produces
four marks out of square by the same amount, and nothing downstream can tell.

So: square the faces by hand FIRST, then sweep. Five steps.

```
   Is the machine empty?              <- confirm; the grippers are about to
   The grippers will close on an         close on an empty centre
   empty centre and turn every face.
   Take the cube OUT before starting.

   U        squared 2013  m0 +3      <- the list. Six motors and a Save row.
   R                1502  m1 -118       Wheel scrolls, SELECT enters a row.
   F                 877  m2 +9         After the raw angle: the nearest
   D            err -1                  STORED mark and the signed error to
   L                3011  m3 -2         it, in counts — what the aligner homes
   B                1244  m0 +0         to. An encoder fault is a fault, not
   Save calibration  4 of 6 squared     a plausible number.

              +3 steps   m0 +3       <- the dial, for one motor. Wheel steps
                  ( 2013 )              it; SELECT accepts, LEFT does not.
                   Motor U              Headline: steps jogged, nearest mark,
         marks 2013 3037 4061 989       error. Sub-line: the four stored marks
                                        the sweep will replace.
```

The mark readouts exist so a face squared by eye can be checked against what
the machine will actually home to, and so "what does home currently mean for
this motor" is answerable from the panel. "m1 -118" is a face 118 counts
(~10 degrees) off its mark; both values come from `CubeSystem::encError()`
over `MotorEncoder::getCalibration()`, the aligner's own test, so the screen
and the aligner cannot disagree. Blank until a calibration exists.

**Rows, not bars, and this is the exception that proves the rule.** Every row of
the list IS a choice, which is what bar art is for — but bars have five slots
and this list has seven, so they cannot be used at all. The cursor is a marked
row instead, exactly as the jog page next door does it. Seven rows is the whole
of `kOpLines` and they only fit with no headline and no sub-line, which is the
Motor Sensors page's shape.

**The clamp is the same three lines as Loading and ModeClamp** — bottom, ring,
top — and honours the abort latch the same way. Every exit from the flow, LEFT
or chord or fault, RELEASES: the flow shut the grippers and the menu has no
idea it happened.

**What SELECT means on the dial** is worth writing down because it is a real
fork. It accepts the motor's PHYSICAL alignment and writes nothing; the Save
row's sweep is what produces all twenty-four calibration values. The other
reading — SELECT writes the current reading through
`MotorEncoder::setCalibration()` — would be overwritten by the sweep moments
later, which makes the dial ceremonial. The physical alignment survives to the
sweep because `resetMotorPos()` only zeroes the step counters; it commands no
travel.

One detent is one step: at 100 steps per quarter turn and 4096 encoder counts
per revolution that is about 10 counts, half the alignment tolerance the
machine works to. It was two steps — one tolerance — until the bench found
that too coarse to centre a face inside the band rather than at one edge of
it, and the sweep's four marks are only as square as the dial left them.
45 degrees out is 50 detents, which nobody squares a face from.

The dial page owns its input like the jog page and the tuning editor, and for
the same reason — the wheel steps a motor there, and `pollEvent()` collapses
the wheel and the UP/DOWN buttons into one meaning.

### Stats — top level — **BUILT**

Six rows — solves, best, average, last, run time, faults — which is exactly
enough, so resist a seventh. The numbers are real now: an EEPROM block of
counters (`CubeStats`), a block of ITS OWN rather than a corner of the tuning
one: solve counts change every run and tuning changes almost never, so sharing
would rewrite the tuning bytes on every solve for nothing.

Solves is one tally, machine-paced and step solves together (the split lives
only in EEPROM, keeping the untimed step solves out of the timed numbers).
Best and Average speak only for solves longer than `kStatMinMoves` — a
three-move touch-up finishing in seconds is not a record — and Best carries
the move count of the solve that set it. The page owns its input (see
`statsLoop()`): SELECT+RIGHT held five seconds resets everything, with a
countdown on the status line, because a five-second hold with no feedback is
indistinguishable from a dead button.

---

## Build order, as it happened

Roughly in this order:

- **Patterns** — the four states and the preview pane came first; the move
  sequences now run, gated on a solved cube.
- **Scramble Solve** — the two phases with one bar throughout. (It was built
  to recolor between them; it is red end to end since the frame became
  wayfinding.)
- **Step Solve** — the ribbon works and the moves execute, one per SELECT.
- **Demo Mode** — scramble and solve on a loop with a run counter, showing the
  moves rather than only a count.
- **Color Sensors** and **Motor Sensors** — real sensor reads, **throttled** and
  round-robin: every refresh is I²C traffic on the bus the wheel is also using.
- **Hardware Test** — the Actuators page, ported into the firmware's
  Diagnostics menu.
- **Tuning** — six sections editing the real values, with defaults in the
  source and overrides in EEPROM, persistence and reset included.
- **Color as wayfinding** — one color per branch, carried out of the menu and
  through the operation screens, plus the Settings reshuffle above.

**Every screen is now drawn AND wired.** `Test_Menu` covers the whole tree, and
its `Screens > Modes` submenu is deliberately the same five items in the same
order as the firmware's `Modes` menu — a rehearsal that groups things
differently from the machine stops being a rehearsal.

The machine side landed too, in the two kinds this section predicted:

1. **Two EEPROM stores**, both the shape `CubeTuning` already is — the
   `CubeFaultLog` ring buffer (replacing the one-int `CubeSystem::lastFault`)
   and the `CubeStats` counters.
2. **Behaviour behind the five Modes**, plus the finished Diagnostics screens
   ported into the firmware sketch. No menu item says "Not implemented yet"
   any more.

Low-confidence marking on the Cube State net can still slot in whenever; it
needs no new primitive, only `scanConf` plumbed through.

## Where to build them

**In `Code/Test Code/Test_Menu`, first.** Not in the firmware.

That sketch needs no cube, no machine and no solver, its `Screens` submenu draws
every operation screen from canned data, and it runs in the simulator:

```sh
cmake -S Code/sim -B Code/sim/build-test -DSIM_SKETCH=Test_Menu
cmake --build Code/sim/build-test -j && ./Code/sim/build-test/cubesim
```

A screen prototyped there can be judged against every frame color and item
count in seconds, and it keeps half-finished UI out of the sketch that drives
real motors. Move it into the firmware once it looks right and there is
something behind it to show.

The corollary matters too: when a screen changes in the firmware, the demo in
`Test_Menu` should follow. The bench sketch being *behind* the firmware is how
it stops being useful. Anything shared — the required calibration orientation,
the scan pass labels — should be referenced from `CubeSystem`'s constants rather
than copied, so the demo cannot drift from the machine.

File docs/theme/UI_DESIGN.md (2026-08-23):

# Panel UI — design notes

How to add to the 320x240 menu without it looking bolted on, and the traps that
will cost you an afternoon if you meet them cold. Read this before writing any
`lv_*` call.

The short version: **the UI is a baked theme, not drawing code.** Almost nothing
is drawn with LVGL primitives. Shapes come from images generated out of the
design files; code positions them and swaps text. If you find yourself reaching
for `lv_obj_set_style_*` to draw a new *shape*, you are probably about to make
something that does not match — bake it instead.

---

## 1. Where everything lives

| What | Where |
|---|---|
| Design source of truth | `docs/theme/melee-menu-lvgl-preview.html` (native 320x240) |
| Full-resolution master | `docs/theme/melee-menu-mockup.html` (1200x900) |
| Asset baker | `Code/tools/bake_theme.py` |
| Generated assets + fonts | `Code/libraries/CubeSolver/utility/` |
| Generated placement constants | `Code/libraries/CubeSolver/utility/CubeThemeAssets.h` |
| Renderer | `Code/libraries/CubeSolver/CubeDisplay.{h,cpp}` |
| Menu engine (no LVGL) | `Code/libraries/CubeSolver/CubeMenu.{h,cpp}` |
| Menu tables + screens | `Code/Main Code/CubeSolver/CubeSolver.ino` |
| Operation sequence shape | `Code/libraries/CubeSolver/CubeOpShape.cpp` |
| Desktop simulator | `Code/sim/` — see its README |

---

## 2. The visual language

**The frame band is the identity.** One continuous band around the content,
recolored as you move. In a menu it takes the color of the **selected item** —
turning the wheel recolors the whole frame. It is the one piece of state
readable from across the room, so it is worth keeping honest.

**The color says WHERE YOU ARE, not what the machine is doing.** A branch of
the menu tree is one color from the row that opens it, down through its
submenus, and out through the operation screens that branch leads to. Yellow
means "somewhere under Settings" whether you are reading About or watching a
motor calibration sweep. This is the Melee menu the design is modelled on,
where the whole Options branch is one color and the whole Trophies branch is
another.

| Theme | Fill | Edge | Branch |
|---|---|---|---|
| Blue | `#1D2680` | `#6D7CF0` | main menu, Load & Scan, Solve — the main line of work. Also Demo Mode |
| Red | `#6E1A10` | `#F0603A` | Modes, and Scramble Solve. Also every Error screen, always |
| Green | `#14522A` | `#4ADE70` | Eject Cube. Also Patterns |
| Yellow | `#6E5A10` | `#E8CF3A` | Settings and its entire subtree. Also Idle Mode |
| Purple | `#33176E` | `#8A62E8` | Stats. Also Step Solve |
| Violet | `#4A1A72` | `#AE6AF0` | no branch — kept for the Idle Mode cycle and for a future one |

Modes is the branch that fans out: the screen is red, but each of the five
modes owns a color and keeps it through its own operation screens. A running
mode is somewhere you can be for minutes, and the five are five different
things that happen to be filed together.

**This replaced an older rule**, which was that the frame reported machine
state — blue scanning, violet calibrating, green solving. The two schemes
fought over one band: the menu already recolored by selection, so a solve
launched from a blue row turned green for no reason the operator could see.
Wayfinding won. `CubeDisplay::OpKind` still maps `Scan`→Blue, `Solve`/`Done`→
Green, `Calibrate`→Violet, `Info`→Yellow, but that mapping is now only the
fallback for a caller that has not named a branch.

**Two exceptions, and only two.**

- **`Error` is red, always**, overriding the branch. A fault has to be
  unmistakable, red already means "stopped" everywhere in this machine, and a
  blue solve that failed into a blue screen would say nothing went wrong.
  Enforced in `CubeDisplay::setOpTheme()`, which refuses to repaint an Error
  screen, rather than left to callers to remember.
- **Idle Mode cycles all six colors**, one per move, on purpose: it is the
  screen whose whole job is looking alive from across a room. Idle Mode's
  *other* screens — the clamp, the solve it hands off to — wear its yellow.

**How a screen gets its color.** `CubeSolver.ino` keeps `s_opTheme`, set in
one place: `loop()` copies `CubeMenu::themeOf()` off the row under the cursor
just before `Menu.handle()` runs it. Every operation screen goes through the
sketch's `opScreen()` helper, which calls `showOperation()` and then
`setOpTheme(s_opTheme)`. So a new screen inherits its branch's color by
existing, and nothing in the sketch calls `showOperation()` directly.

**Typography** — five baked fonts, each with one job. Do not introduce a sixth
without a reason; each costs ~20-40 KB of flash.

| Font | Face | Used for |
|---|---|---|
| `lv_font_title_13` | Anton 13 | screen title, top-left at (52, 21) |
| `lv_font_head_16` | Fira Sans Cond. Bold 16 | operation headline |
| `lv_font_bar_12` | Fira Sans Cond. Bold 12 | menu bar labels, status rows |
| `lv_font_desc_11` | Anton 11 | the description/hint box |
| `lv_font_prev_9` | Fira Sans Cond. Bold 9 | preview pane, chip row labels |

**The baked fonts carry ASCII only** — `0x20-0x7F`, which is what the baker asks
`lv_font_conv` for. Arrows, angle quotes and box-drawing characters are not in
them, and a missing glyph draws as a blank box with no complaint (see 4.5). Use
`<` and `>`, not `‹` and `›`, or widen the range in `bake_theme.py` and accept
the flash.

**The description box is always the bottom line.** 182x21 at (69, 199). In a
menu it carries the selected item's caption; on an operation screen it carries
the hint ("Press SELECT", "SELECT+LEFT to abort"). Same box, same place, always
— that consistency is most of why operations do not feel like a different
program.

**The cursor means "this is the one".** Orb + inward sonar rings + spinning
comma. It marks the selected menu item. Do not use it decoratively.

**Bar art means "you can select this".** The glowing bar with the socket is the
menu's vocabulary for a *choice*. It was briefly reused to show scan progress
and the result read as a screen full of buttons that did nothing — the shape
promised an interaction that was not there. Status belongs to chips, the
progress bar, the status table or plain text. When something genuinely is a list
of choices, bars are right and should be used.

`docs/theme/SCREEN_PLAN.md` records how every screen was designed — Patterns,
Idle, Step Solve, Cube State, Parameters and the rest — and which shared pieces
exist. Read it before designing a new screen or changing one; the piece you
want may already be built.

---

### The dial vs the progress bar

Both are round-ish things that fill up, and they say opposite things.

| | Progress bar | Dial |
|---|---|---|
| Means | how far through a job | where a SETTING sits in its range |
| Driven by | the machine | the wheel |
| While it moves | you wait | you are turning it |

A screen showing both is claiming two different kinds of "how far along", so
`setOpDial()` and `setOpProgress()` should not appear together — the one place
that could have happened, Idle Mode's solve, hides the dial explicitly.

The dial follows the frame color, so it belongs to the screen rather than
sitting on it. Its caption goes UNDER the arc: the inner diameter is about 60 px
and any caption worth writing is wider, so one placed in the middle draws across
the stroke on both sides.

## 3. Hard limits to design within

These are not style preferences; exceeding them clips, ellipsises or collides.

| Limit | Value | Why |
|---|---|---|
| Menu items per screen | **5** | `kVisibleRows`. The zigzag layout has five slots. A sixth wants a submenu, not a scrollbar. |
| Menu caption | **~34 chars** | 182 px at Anton 11, else ellipsised. |
| Preview entries | **5 max, ~13 chars** | `PREV_W` is 54 px; the pane is a perspective trapezoid whose right border sits near x=282, *not* at the asset's bounding box. |
| Operation body rows | **7** | `kOpLines`, 216 px wide from x=52. Seven, because the machine has seven motor encoders. |
| Calibration chips | **6 colors x 2 boards** | fixed by the hardware. |
| Panel | **320x240, RGB565** | 16-bit color quantises; flat fills and clearly-separated colors hold up, near-neighbour gradients band. |

Row geometry changes with item count: 5 items start at y=70 with a 27 px pitch,
fewer start at y=76 with 29. `CubeDisplay::barBoxPos()` owns this.

---

## 4. Traps that cost real time

### 4.1 Running out of LVGL memory HALTS the machine, silently

`LV_USE_ASSERT_MALLOC` is 1 and LVGL's default assert handler is `while(1);`.
`LV_USE_LOG` is 0. So an exhausted pool is not a degraded UI — it is a hang,
with no message, no crash, nothing on the panel and nothing on Serial.

This has already happened once: adding the operation screens took the peak over
the then-32 KB pool and the firmware hung at boot producing no output at all.

**Rule:** after adding widgets, check the pool. `CubeDisplay::begin()` prints it
over Serial once every widget exists; `M` in the simulator prints it live.
The pool is 64 KB (`LV_MEM_SIZE`); the boot line says how much the widget set
takes — ~35 KB at the last raise. Leave at least 8 KB free — a draw layer needs
it.

### 4.2 A8 images are copied into RAM; RGB565A8 is read from flash

LVGL's bin decoder hands an uncompressed variable-source image straight to the
draw unit *unless* it is alpha-only. `decode_alpha_only()` calls
`lv_draw_buf_create()` and copies the whole image into a fresh `w*h` RAM buffer.

A 255x194 A8 band is 49 KB. It did not fit, so it failed to allocate, so the
frame band simply **never appeared** — silently.

**Rule:** anything recolorable at runtime is baked **RGB565A8** (white pixels +
alpha), never A8. Costs 3 bytes/px instead of 1; that is the whole reason the
asset total is ~565 KB. Flash this project has; RAM it does not.

### 4.3 Assets must live in `utility/`

`Code/libraries/CubeSolver` has no `library.properties`, so the Arduino IDE
treats it as a 1.0-format library and compiles **only the library root and
`utility/`**. Sources anywhere else are silently ignored — the sketch builds and
then fails to link. Do not "tidy" the assets into a prettier subdirectory.

### 4.4 You cannot transform a container

Rotating or scaling an `lv_obj` renders it through a layer, and a *transformed*
layer is allocated whole up front — 150 KB for a full-screen group, ~19 KB for a
single bar box. Neither fits.

Transformed **images** are fine: they stream through a small bounded buffer.
That is why the wheel transition moves each bar along its arc (`placeBarsAt()`)
instead of rotating the group, and why the sonar rings and comma are `lv_image`
widgets rather than styled objects.

### 4.5 Everything fails silently

`LV_USE_LOG` is 0. A missing glyph renders as a blank box, an unallocatable
image renders as nothing, a full pool hangs. **There is no error path that talks
to you.** So: change one thing, look at it in the simulator, then continue.
Never batch five visual changes and build once.

### 4.6 An `lv_image_dsc_t` must be complete BEFORE `lv_image_set_src()`

`lv_image_set_src()` reads the header there and then, to size the widget. Point
it at a descriptor you have not filled in yet and the widget is 0x0 and draws
nothing — silently, of course. This bit the preview-pane cube net: the image was
created up with the menu widgets, and its descriptor was populated later,
alongside the operation-screen ones.

Build the descriptor, then create the image. If a runtime-drawn image is blank,
check that order first.

### 4.7 No C99 compound literals in the sketches

`(char[2]){ c, 0 }` is C99. In C++ it is a GNU extension with different lifetime
rules, and GCC accepts it without a word — the string simply came out empty and
the whole row vanished from the screen. Build the value into a named buffer, or
use a table of `const char*`.

### 4.8 (bonus) `bake_theme.py --no-images` leaves the header stale

`CubeThemeAssets.h` carries both image placement constants and font
declarations, and only the rasterizer can write the image half. If you add a
font, run a **full** bake. The script now says so, but it will not stop you.

---

## 5. What LVGL cannot do here, and what to do instead

| Wanted | LVGL | Do this |
|---|---|---|
| Skewed / italic title | no text transform | bake a title image, or accept upright |
| Per-corner radius | single `radius` | bake the shape (the preview pane is baked for exactly this) |
| Text outline / stroke | none | pick colors with enough contrast, or bake |
| Gaussian glow | none per-frame | bake it into the sprite |
| Vertical text | none | bake it rotated (`theme_next_label`) |
| Perspective | none | bake pre-skewed |

**Deviations already made deliberately — do not "fix" them back:**

- Title and description use **Anton**, a libre stand-in for Impact. The design's
  `skewX(-8deg) scaleY(.84)` on the title is dropped.
- Preview pane text is **upright inside a tilted frame**. Baking the text would
  freeze menu labels into an asset.
- The wheel transition **does not tilt the bars** (see 4.4). The arc paths are
  exact; only per-bar rotation is missing.
- **No leaf-confirm blink.** Every leaf action in this firmware navigates away
  from the menu immediately, so the blink would be drawn and instantly
  overwritten. Add it only if a leaf ever stays put.
- Preview entries are **abbreviated** ("Motor Positions" → "Motors") to fit 54 px.

---

## 6. Recipes

### Add a menu item

Edit the table in `CubeSolver.ino`. Nothing else needs touching.

```c
{ "Label", &kScreenSub, nullptr, "Caption under 34 chars.",
  kPrevSomething, 3 },
```

`submenu` **or** `action`, never both. `preview` non-null spells out what the
submenu contains; leave it null for an item that starts an operation and the
pane draws the placeholder plates instead. Three-field
`{ label, submenu, action }` still compiles — the rest default.

**Omit `theme` unless the item leaves its branch.** Inheriting the screen's is
what keeps a branch one color by construction instead of by every row agreeing,
and the color is now wayfinding (see §2). The tree names a theme in exactly
three places: the top-level rows, the five Modes rows, and the Patterns rows —
and the last of those are a preview device rather than a place, which is why
`actPattern()` overrides `s_opTheme` back to the screen's green.

If a `preview` list is edited, fix the item's `previewCount` and the screen's
`count` in the same breath. They are parallel numbers, not derived ones, and a
stale one either mislabels the pane or walks off the end of the table.

### Add a menu screen

A screen is a table plus a `MenuScreen`. Five items maximum. Give it a theme;
give each item a caption. Add an `extern const MenuScreen` near the top if the
tables reference each other.

### Add an operation screen

```c
showOp(Op::Calibrate, "Servo Calibration", "Setting endpoints", "Do not touch");
```

`showOp()` is `opScreen()` plus the flush; use `opScreen()` if you are about to
decorate and want one repaint rather than two. Either way the frame comes out
the color of the branch you are in — `kind` only names what sort of screen this
is, and picks the fallback color if no branch has been set. Use `Op::Error`
when, and only when, something has gone wrong: it pins the frame red.

Then optionally decorate — these are separate calls because most screens want
only one:

- `cubeDisplay.setOpLines(rows, n)` — up to 7 rows (`kOpLines`). `"Label\tValue"` renders as
  an aligned pair; no tab means a full-width line.
- `cubeDisplay.setOpSteps(labels, n, active, done)` — named steps drawn with the
  menu's own bar art. **Takes over from the headline**, which it hides.
- `cubeDisplay.setOpChips(bits, boards)` — the calibration color grid.
- `cubeDisplay.setOpProgress(done, total)` — a filled bar.

Steps and chips both want the middle of the screen; do not use both at once.

### Report progress from a long operation

The operation lives in `CubeSystem`, which knows how far along it is. Call
`displaySetStatus()` / `displaySteps()` / `displayChips()` / `displayProgress()`
from inside it, then `displayUpdate()`. `setMessage`/`setStatus` update a live
operation screen in place rather than rebuilding it, so they are cheap to call
in a loop.

**Update before the slow part, not after.** A scan pass is ~5.4 s of color
integration; a progress display that updates once it finishes is not a progress
display.

If the sequence has a shape (passes, stages, rotations), put the labels in
`CubeOpShape.cpp`. The simulator replaces `CubeSystem.cpp` but still compiles
that file, which is what stops the simulator drifting from the machine.

### Change the artwork

Edit `docs/theme/melee-menu-lvgl-preview.html`, re-run
`python3 Code/tools/bake_theme.py`, rebuild. Placement constants are measured by
the rasterizer and regenerated, so widgets follow the art without hand-editing
coordinates.

---

## 7. Verifying

The simulator runs the **real firmware** — the same `CubeDisplay`, the same
`lv_conf.h`, the same 64 KB pool. Use it; do not design against the HTML.

```sh
cmake --build Code/sim/build -j && ./Code/sim/build/cubesim --scale 3
```

`P` screenshots to `sim-shot-NN.bmp` (native 320x240, gitignored). `M` prints
the LVGL pool. `C` toggles the cube state to reach both main menus. `F` arms a
fault to reach the error screens.

Driving it from a script has three traps, all documented in `Code/sim/README.md`:
SDL creates more than one X window (try each and keep the one that takes
focus), buttons are level-sampled every 25 ms so a press must be **held**, not
tapped, and focus drifts mid-run. Kill leftover instances with `pkill -x cubesim`
— `pkill -f cubesim` matches your own shell.

For a visual check, render the preview at 320x240 with headless Chrome and
compare side by side. That is how the original port was validated to near
pixel-accuracy.

The menu engine has host-side tests that need no hardware and no LVGL:

```sh
cd Code/tests && g++ -std=c++14 -Wall -Wextra -I../libraries/CubeSolver \
  test_menu.cpp ../libraries/CubeSolver/CubeMenu.cpp -o /tmp/test_menu && /tmp/test_menu
```

**The Teensy build is not verifiable from the simulator.** `CubeSystem.cpp` is
not compiled there at all. A useful stopgap for edits to it:

```sh
g++ -fsyntax-only -std=c++17 -DLV_CONF_INCLUDE_SIMPLE -ICode/sim/shim \
  -ICode/libraries/CubeSolver -ICode/libraries -ICode/libraries/kociemba \
  -ICode/sim/build/_deps/lvgl-src -ICode/sim/build/_deps/lvgl-src/src \
  Code/libraries/CubeSolver/CubeSystem.cpp
```

---

## 8. Budgets

| Resource | Used | Of |
|---|---|---|
| Theme assets (flash) | ~565 KB | ~3.3 MB free after the solver's 4.14 MiB of tables |
| Generated source | 3.7 MB of `.c` | committed, like the kociemba tables |
| LVGL pool | ~35 KB after UI build (see the boot line) | 64 KB (`LV_MEM_SIZE`) |
| Framebuffers (RAM) | ~195 KB | 1 MB on a Teensy 4.1 |

Flash is plentiful, the LVGL pool is not. When adding widgets, prefer reusing
existing ones: the operation screens reuse the menu's bar art for step rows and
`lbl_msg`/`lbl_status`/`box_desc` for the headline, sub-line and hint bar, which
is why they cost almost nothing.

Widgets are created **once** in `buildUi()` and shown/hidden thereafter — never
created and deleted per screen. Churning LVGL objects at menu speed fragments
the pool, and the failure mode of that is 4.1.

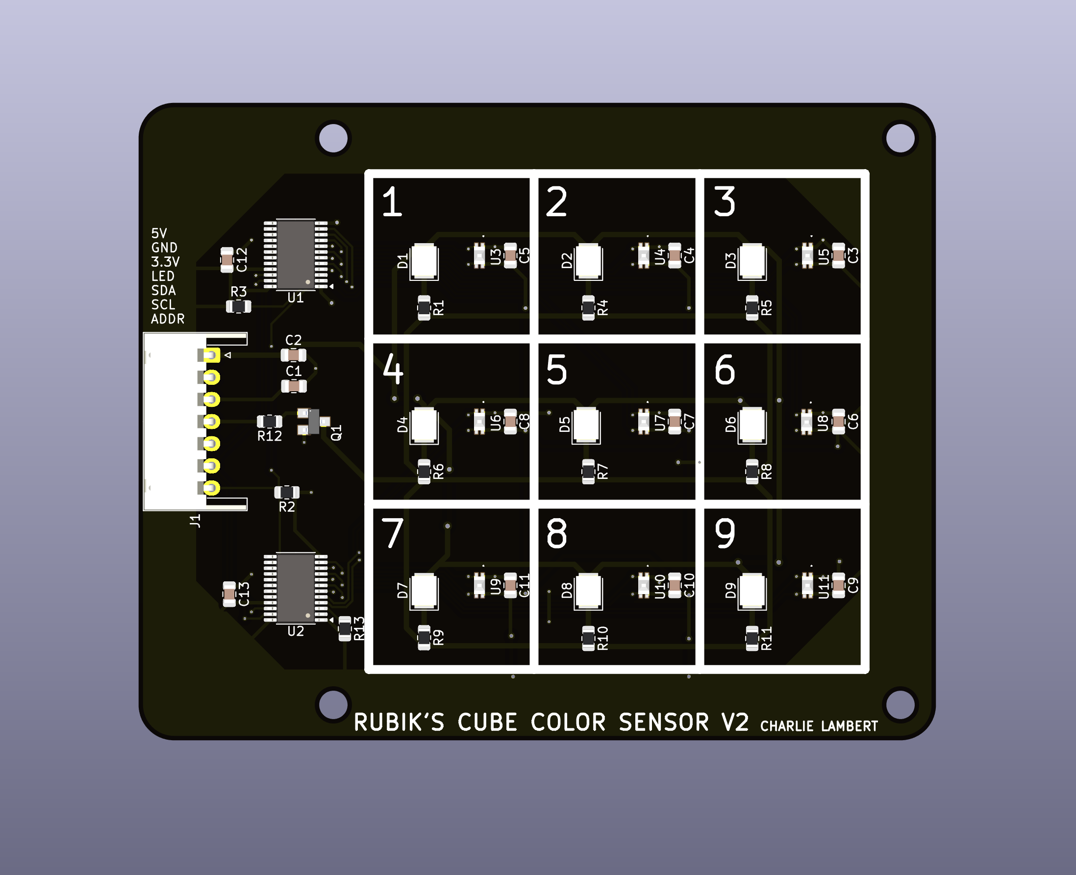
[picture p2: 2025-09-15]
Circuitry/KiCad/Cube Solver/Color Sensor/Drawings and Graphics/Color Sensor Top View.png

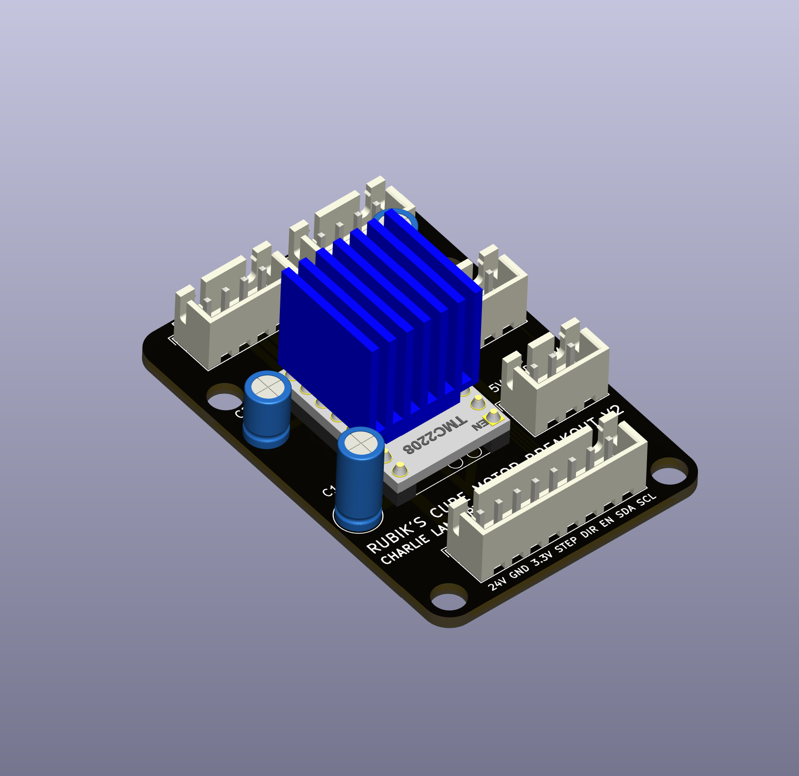
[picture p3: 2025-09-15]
Circuitry/KiCad/Cube Solver/Motor Breakout/Drawings and Graphics/Motor Breakout Ortho.png

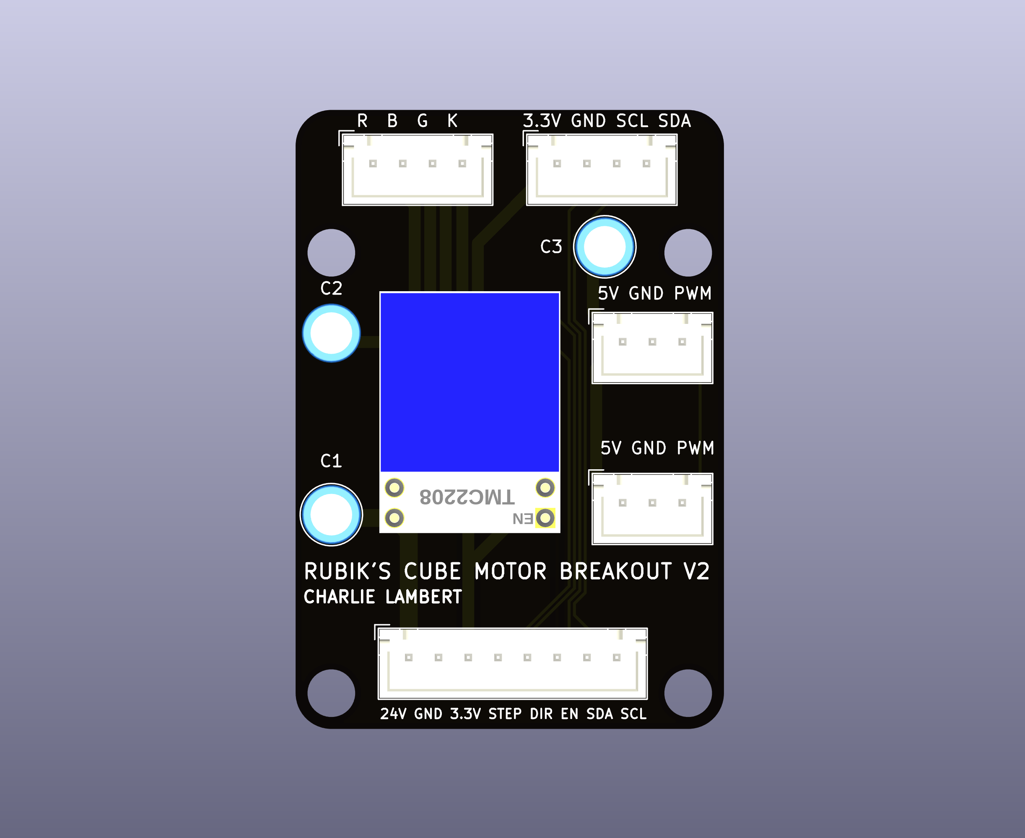
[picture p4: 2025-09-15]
Circuitry/KiCad/Cube Solver/Motor Breakout/Drawings and Graphics/Motor Breakout Top View.png

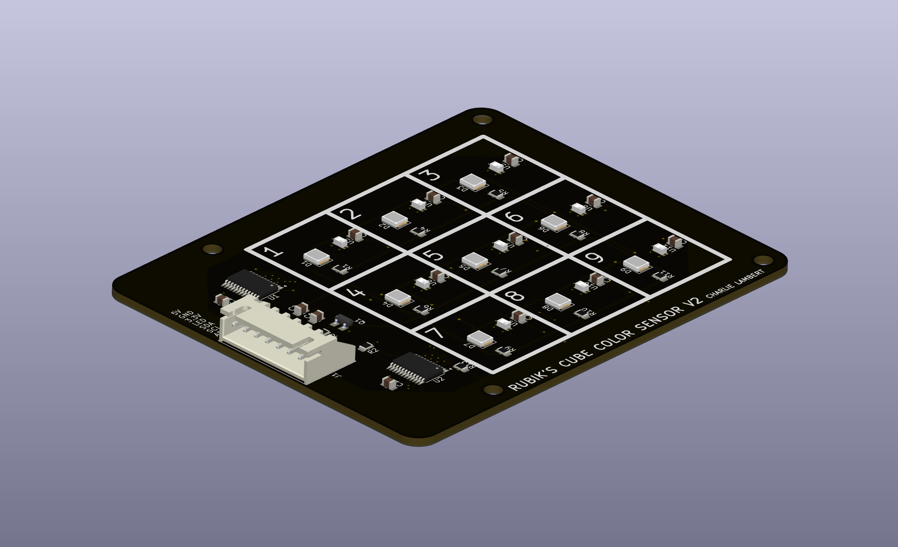
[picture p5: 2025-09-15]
Circuitry/KiCad/Cube Solver/Color Sensor/Drawings and Graphics/Color Sensor Ortho View.png

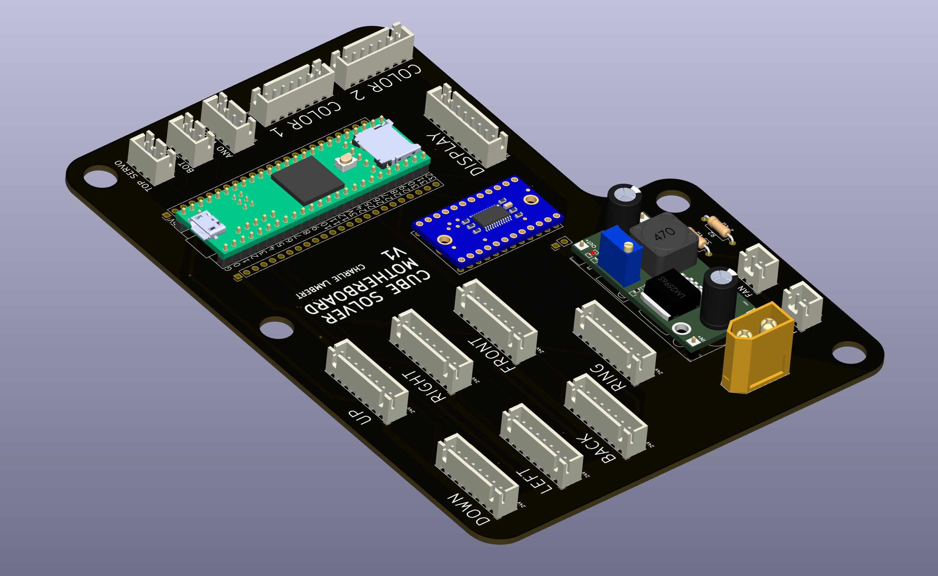
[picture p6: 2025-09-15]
Circuitry/KiCad/Cube Solver/Motherboard/Drawings and Graphics/Motherboard_Ortho_View.png

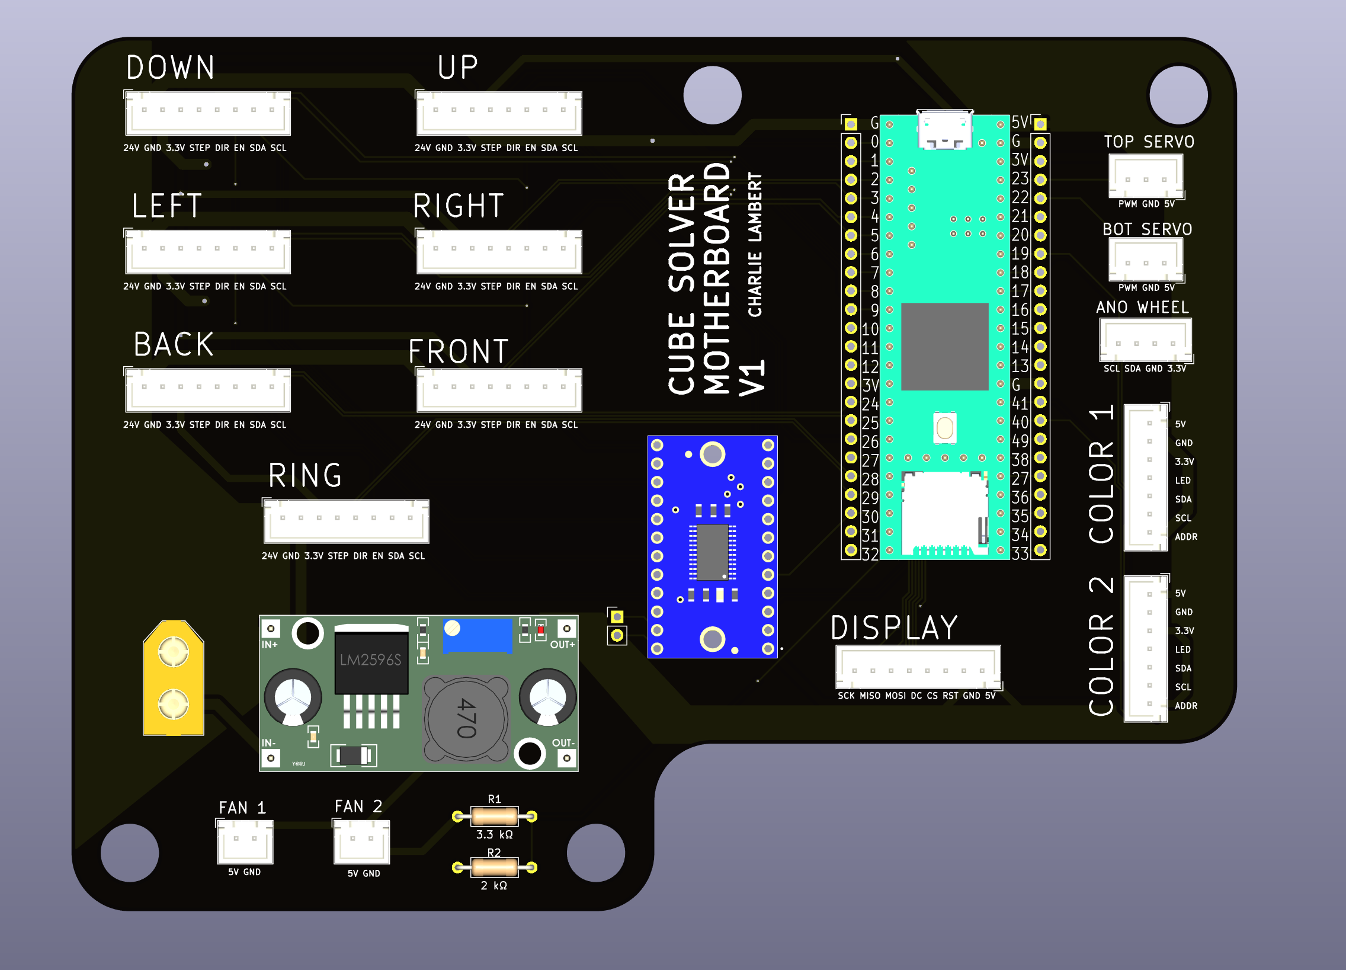
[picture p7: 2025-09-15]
Circuitry/KiCad/Cube Solver/Motherboard/Drawings and Graphics/Motherboard_Top_View.png

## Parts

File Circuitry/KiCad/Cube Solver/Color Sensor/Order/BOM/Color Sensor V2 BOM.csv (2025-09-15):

Id | Designator | Footprint | Quantity | Designation | Supplier and ref
1 | U4,U5,U6,U7,U8,U9,U10,U11,U3 | VISHAY_VEML6040_1.25X2X1 | 9 | VEML6040
2 | D1,D5,D9,D7,D3,D2,D6,D4,D8 | LED_PLCC_2835 | 9 | GW JTLMS3.GM-G6GV-XX55-1-60-R33
3 | C5,C11,C13,C7,C4,C10,C3,C6,C8,C9,C12 | C_0805_2012Metric | 11 | 0.1µF
4 | R4,R6,R5,R10,R7,R11,R9,R1,R8 | R_0805_2012Metric | 9 | 100Ω
5 | C1,C2 | C_0805_2012Metric | 2 | 10µF
6 | U2,U1 | TSSOP-24_4.4x7.8mm_P0.65mm | 2 | TCA9548APWR
7 | R12 | R_0805_2012Metric | 1 | 330Ω
8 | R2,R3,R13 | R_0805_2012Metric | 3 | 10kΩ
9 | Q1 | SOT23 | 1 | MMBT2222A
10 | J1 | JST_XH_S7B-XH-A-1_1x07_P2.50mm_Horizontal | 1 | Color Sensor Input

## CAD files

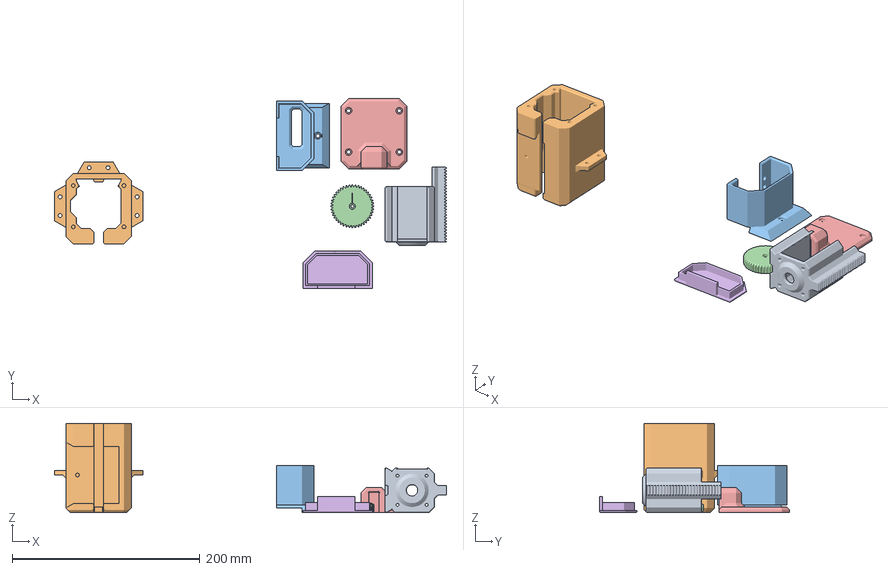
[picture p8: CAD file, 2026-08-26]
3D Models/6-Top Motor Subassembly/3D Printing/Top Motor Assembly Print.3mf
417.4 x 202.3 x 95.0 mm
Top Motor Bracket.STL
Top Motor Track.STL
Top Servo Bracket.STL
Top Servo Pinion.STL
Top Motor Track Cap.STL
Top Servo Bracket Cap.STL

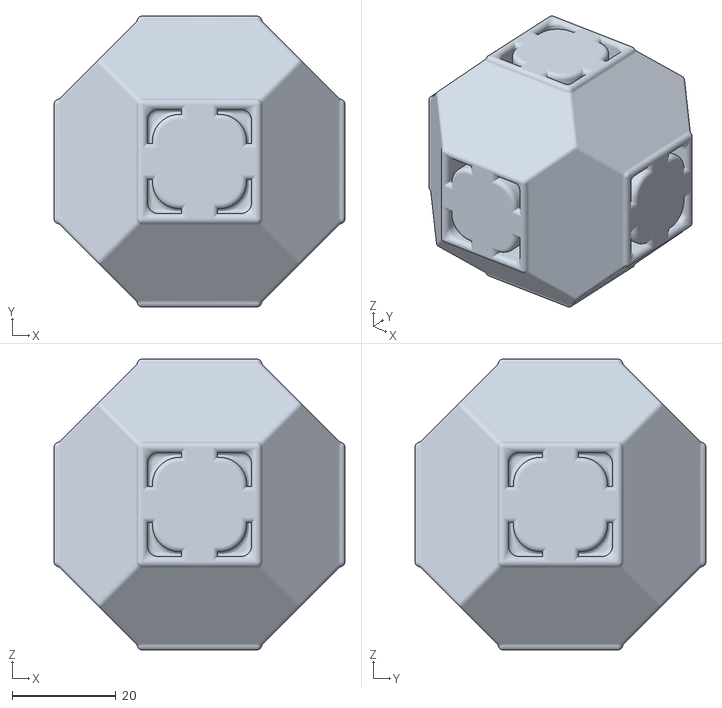
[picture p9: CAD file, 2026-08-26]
3D Models/1-Basic Motor Components/3D Printing/Calibration Cube.STL
56.0 x 56.0 x 56.0

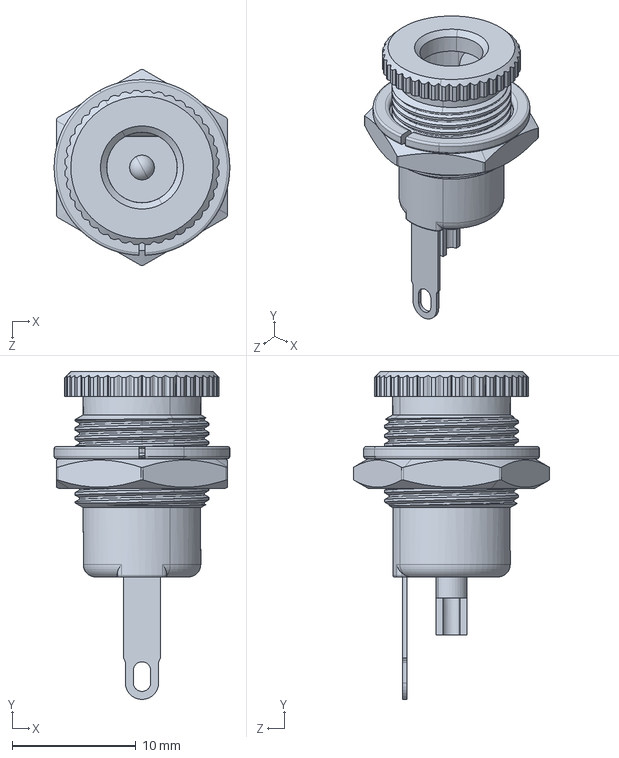
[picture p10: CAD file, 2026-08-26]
3D Models/11 - Misc Parts/Barrel Jack.SLDPRT
14.2 x 26.5 x 15.9 mm

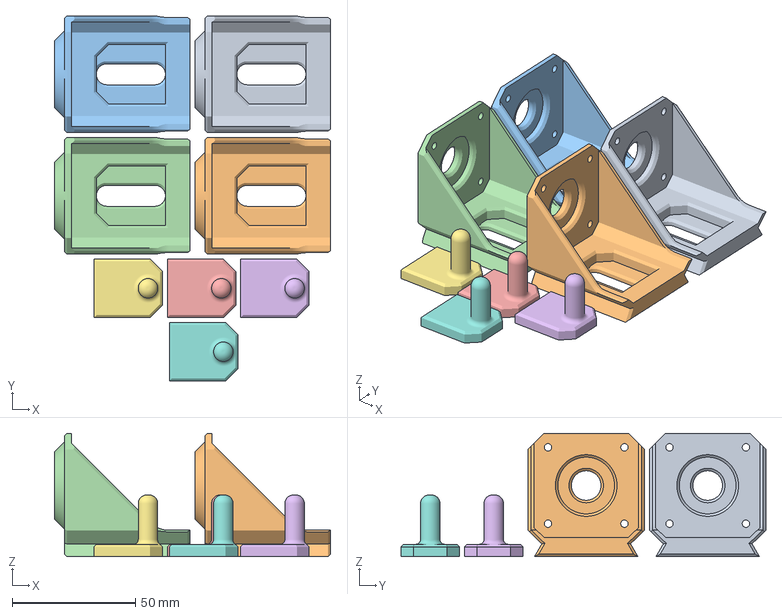
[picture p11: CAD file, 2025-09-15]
3D Models/2-Side Motor Components/3D Printing/Side Motor Brackets + Pins.3mf
112.0 x 148.1 x 50.0 mm
Side Motor Bracket.STL x 4
Side Motor Track Pin.STL x 4

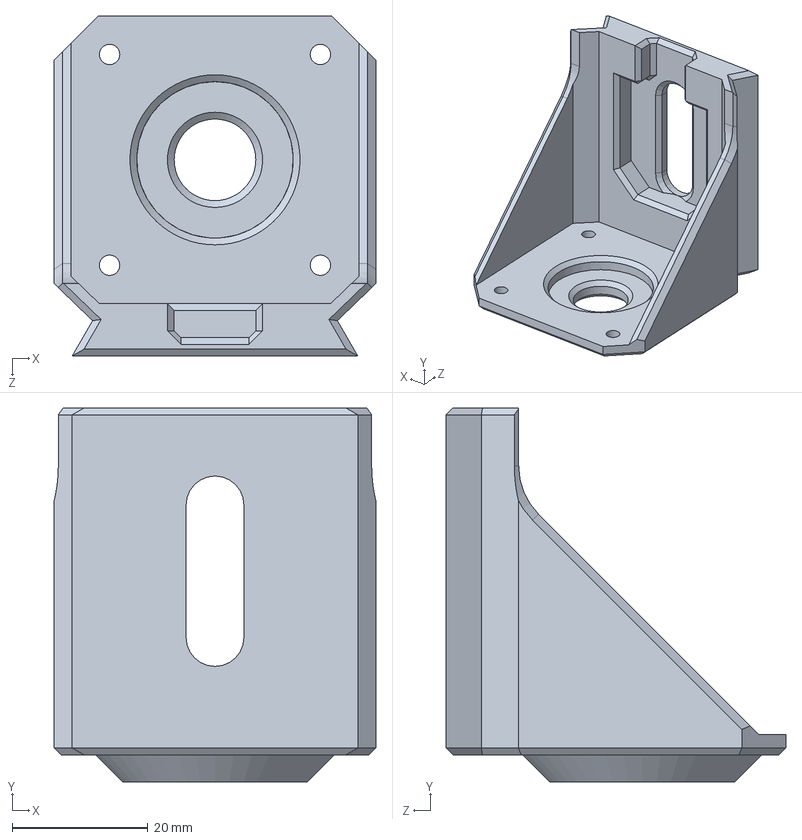
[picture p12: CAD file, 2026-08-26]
3D Models/2-Side Motor Components/Side Motor Bracket.SLDPRT
47.3 x 55.0 x 50.0 mm

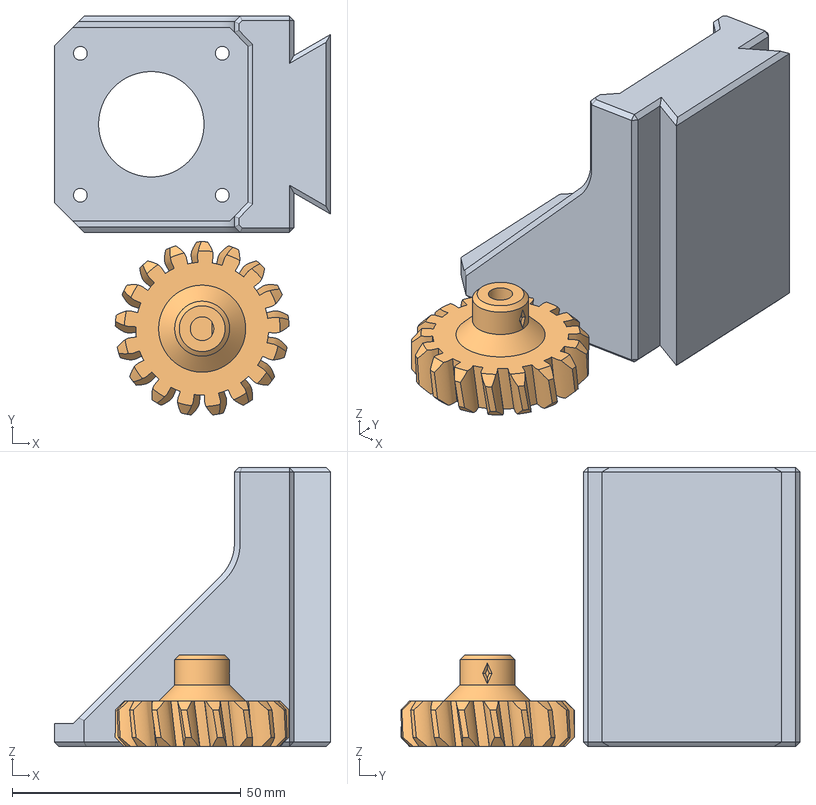
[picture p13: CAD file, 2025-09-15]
3D Models/3-Ring Track Components/3D Printing/Ring Motor Parts.3mf
60.3 x 87.2 x 61.0 mm
Ring Motor Bracket.STL
Track Driver Gear.STL

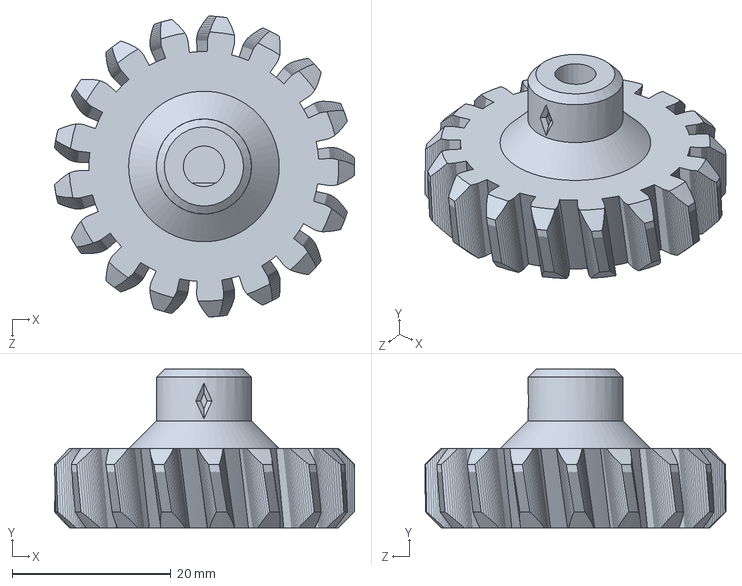
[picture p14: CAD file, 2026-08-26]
3D Models/3-Ring Track Components/Track Driver Gear.SLDPRT
37.9 x 20.0 x 38.0 mm

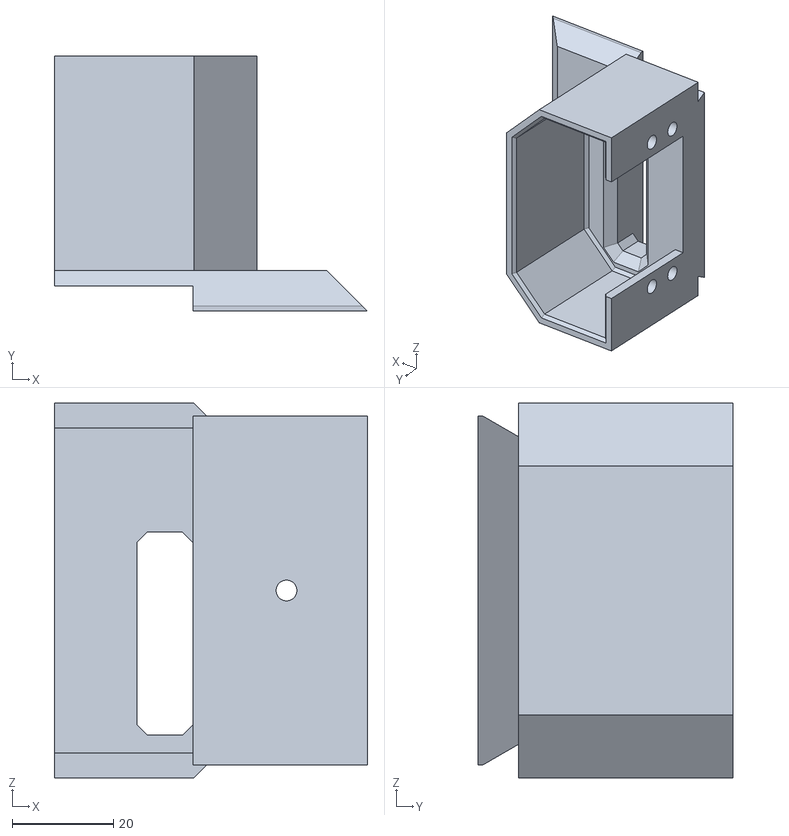
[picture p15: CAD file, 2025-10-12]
3D Models/5-Bottom Motor Subassembly/3D printing/Bottom Servo Bracket New.STL
61.8 x 50.4 x 74.0

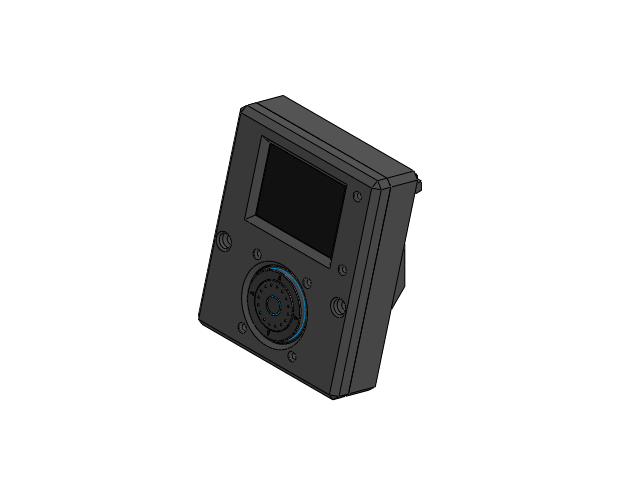
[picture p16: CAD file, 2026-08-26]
3D Models/10 - Display Mount/Display Panel Assembly.SLDASM
Display Panel
2.2 TFT LCD Display Modul 240x320
5221 ANO Rotary Encoder
Display Panel Mount

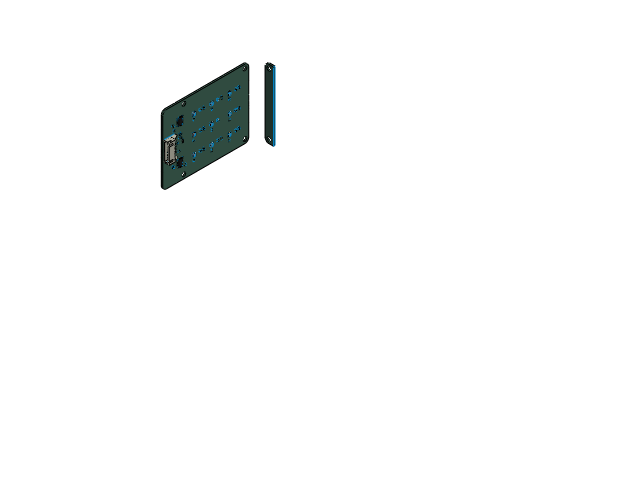
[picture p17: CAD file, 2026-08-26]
3D Models/4-Color Sensor Subassembly/Color Sensor Subassembly.SLDASM
Color Sensor Body
Color Sensor x 2

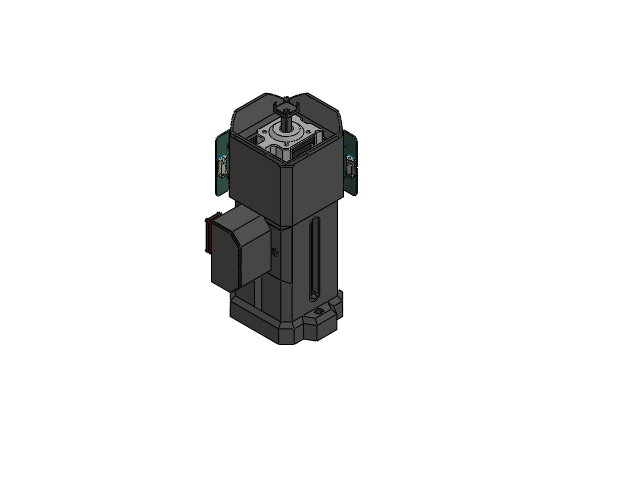
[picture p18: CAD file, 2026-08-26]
3D Models/5-Bottom Motor Subassembly/Bottom Motor Assembly.SLDASM
Bottom Motor Track
Bottom Motor Bracket
Cube Holder
Encoder Bracket
Disk Magnet
AS5600
NEMA17-Stepper.step
Bottom Servo Bracket
LewanSoul LD-20M Servo 20kg
Bottom Servo Pinion
Bottom Servo Bracket Cap
Bottom Motor Track Stand
Color Sensor Body
Color Sensor x 2

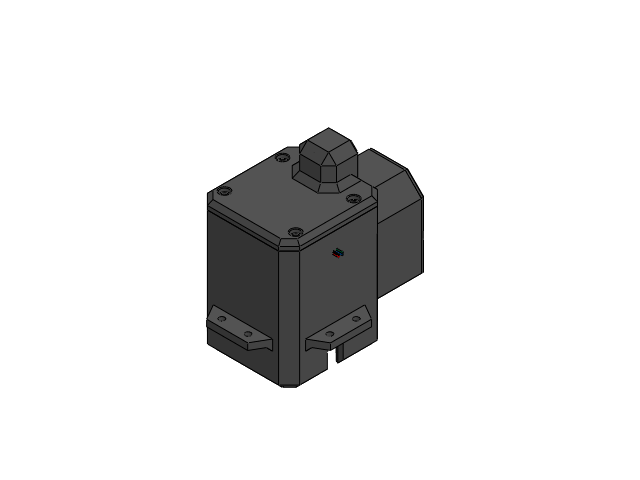
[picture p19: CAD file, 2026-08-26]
3D Models/6-Top Motor Subassembly/Top Motor Assembly.SLDASM
Top Motor Track
Top Motor Bracket
Encoder Bracket
Disk Magnet
AS5600
NEMA17-Stepper.step
Cube Holder
Top Servo Bracket
LewanSoul LD-20M Servo 20kg
Top Servo Pinion
Top Servo Bracket Cap
Top Motor Track Cap

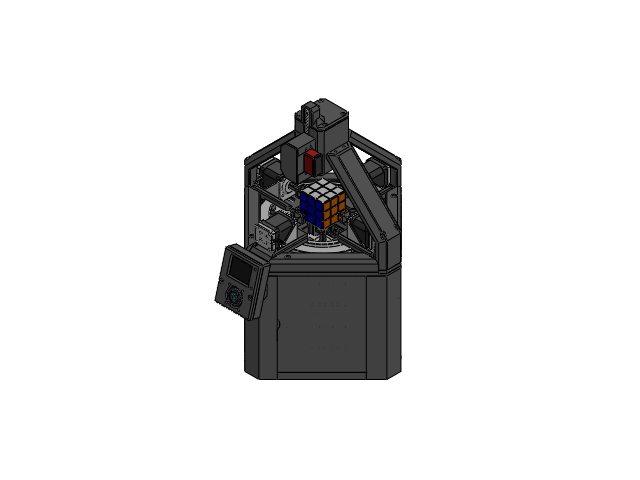
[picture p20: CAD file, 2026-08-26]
3D Models/Cube Solver Full Assembly.SLDASM
NEMA17-Stepper.step x 7
Cube Holder x 18
Side Motor Bracket x 4
Side Motor Track Pin x 4
Side Motor Track x 4
Side Motor Lower Mount x 4
Encoder Bracket x 7
AS5600 x 7
Disk Magnet x 7
Side Motor Ring Track
Top Perimeter Frame x 3
Corner Column x 4
Motor Breakout x 7
Bottom Perimeter Frame x 4
Door Hinge Peg x 8
Hinge Doors x 4
Circle Track Cover x 4
Track Driver Gear
Ring Motor Bracket
Motherboard
Motherboard Holder x 4
Rocker Switch KCD1
Barrel Jack
Noctua-NF-A4x10 v1.stp
Noctua nf-a8-pwm fan 80x80x25 v2.stp
Floor
Bottom Motor Track
Bottom Motor Bracket
Bottom Servo Bracket
LewanSoul LD-20M Servo 20kg x 2
Bottom Servo Pinion
Bottom Servo Bracket Cap
Bottom Motor Track Stand
Color Sensor Body
Color Sensor x 2
Top Motor Holder Frame x 3
Top Motor Track
Top Motor Bracket
Top Servo Bracket
Top Servo Pinion
Top Servo Bracket Cap
Top Motor Track Cap
Display Panel
2.2 TFT LCD Display Modul 240x320
5221 ANO Rotary Encoder
Display Panel Mount
Cube Holder Press

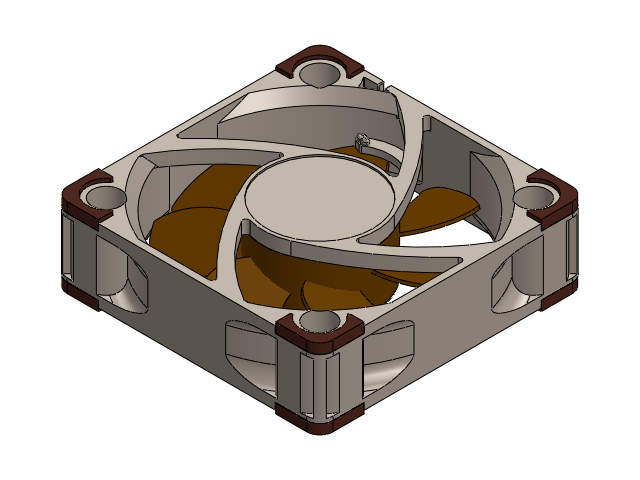
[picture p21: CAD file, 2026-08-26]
3D Models/11 - Misc Parts/Noctua-Fan-NF-A4x10_40mm.SLDASM
Noctua-NF-A4x10 v1.stp
Noctua nf-a8-pwm fan 80x80x25 v2.stp

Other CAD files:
3D Models/7-Frames and Columns/Corner Column PCB Assembly.SLDASM
3D Models/3-Ring Track Components/Ring Motor Assembly.SLDASM
3D Models/2-Side Motor Components/Side Motor Assembly.SLDASM
3D Models/1-Basic Motor Components/Cube Holder Press.SLDPRT
3D Models/1-Basic Motor Components/3D Printing/Encoder Bracket.STL
3D Models/1-Basic Motor Components/3D Printing/_Archive/Cube Holder 6-27-2024.STL
3D Models/1-Basic Motor Components/3D Printing/_Archive/Cube Holder Bigger 6-27-2024.STL
3D Models/1-Basic Motor Components/AS5600.SLDPRT
3D Models/1-Basic Motor Components/Cube Holder.SLDPRT
3D Models/1-Basic Motor Components/Disk Magnet.SLDPRT
3D Models/1-Basic Motor Components/Encoder Bracket.SLDPRT
3D Models/1-Basic Motor Components/NEMA17-Stepper.step.SLDPRT
3D Models/1-Basic Motor Components/Rotary Potentiometer.SLDPRT
3D Models/10 - Display Mount/2.2 TFT LCD Display Modul 240x320.SLDPRT
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

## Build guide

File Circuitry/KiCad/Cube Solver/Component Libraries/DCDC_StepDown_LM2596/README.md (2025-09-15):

KiCad library for the LM2596 buck/step-down module

3D models come in two formats : STEP and WRL, in a ZIP archive, files being too large for GitHub.

3D models : bare module, and model with pin headers



Symbol :



Footprint :



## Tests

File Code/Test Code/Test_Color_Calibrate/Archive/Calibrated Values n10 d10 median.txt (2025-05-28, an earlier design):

Color Sensor 1
1 - Sensor 0:
  R: 112	98	18	196	
  G: 51		126	14	167	
  B: 47		76	17	108	
  Y: 155	184	17	241	
  O: 129	147	14	239	
  W: 171	211	14	243	
  E: 67		65	56	81	

1 - Sensor 1:
  R: 92		57	27	154	
  G: 30		73	35	129	
  B: 23		36	34	79	
  Y: 123	119	62	241	
  O: 108	98	48	237	
  W: 145	147	75	242	
  E: 44		43	37	57	

1 - Sensor 2:
  R: 122	79	41	147	
  G: 54		102	59	147	
  B: 47		64	57	124	
  Y: 146	143	84	150	
  O: 137	118	65	149	
  W: 147	147	103	151	
  E: 67		62	56	85	

1 - Sensor 3:
  R: 104	42	24	176	
  G: 31		72	42	152	
  B: 22		35	41	104	
  Y: 177	135	73	243	
  O: 144	105	55	241	
  W: 185	147	88	243	
  E: 63		67	56	90	

1 - Sensor 4:
  R: 95		64	18	191	
  G: 26		91	32	161	
  B: 21		48	30	112	
  Y: 147	149	56	243	
  O: 122	115	41	241	
  W: 159	179	70	243	
  E: 33		34	28	50	

1 - Sensor 5:
  R: 124	71	17	200	
  G: 30		92	35	150	
  B: 21		41	28	88	
  Y: 184	162	72	243	
  O: 159	148	60	243	
  W: 204	185	64	244	
  E: 78		75	63	111	

1 - Sensor 6:
  R: 76		57	17	168	
  G: 27		79	33	158	
  B: 26		47	32	121	
  Y: 127	137	63	242	
  O: 110	120	52	241	
  W: 140	157	65	243	
  E: 36		38	34	52	

1 - Sensor 7:
  R: 86		58	18	176	
  G: 28		85	36	165	
  B: 27		49	35	127	
  Y: 140	148	71	243	
  O: 122	126	57	242	
  W: 150	170	76	243	
  E: 23		24	20	38	

1 - Sensor 8:
  R: 74		45	11	143	
  G: 24		71	27	135	
  B: 19		37	25	95	
  Y: 126	130	55	242	
  O: 109	111	42	240	
  W: 139	152	61	243	
  E: 15		17	15	35	

Color Sensor 2
2 - Sensor 0:
  R: 71		36	7	114	
  G: 15		49	19	85	
  B: 15		26	18	60	
  Y: 120	107	53	240	
  O: 100	92	41	222	
  W: 124	110	41	239	
  E: 61		54	45	89	

2 - Sensor 1:
  R: 75		30	7	118	
  G: 16		39	18	79	
  B: 20		23	21	71	
  Y: 120	88	51	238	
  O: 104	73	39	217	
  W: 123	91	48	239	
  E: 39		31	27	62	

2 - Sensor 2:
  R: 63		0	7	74	
  G: 15		0	17	35	
  B: 18		0	20	41	
  Y: 97		0	41	144	
  O: 84		0	31	121	
  W: 112	0	49	167	
  E: 16		11	12	27	

2 - Sensor 3:
  R: 78		51	21	154	
  G: 16		63	31	115	
  B: 19		45	41	108	
  Y: 124	120	66	240	
  O: 120	118	60	240	
  W: 128	134	71	241	
  E: 51		51	45	87	

2 - Sensor 4:
  R: 57		31	11	106	
  G: 11		35	15	64	
  B: 11		23	17	57	
  Y: 93		72	34	210	
  O: 91		76	32	208	
  W: 94		78	34	219	
  E: 36		31	28	58	

2 - Sensor 5:
  R: 63		31	16	119	
  G: 15		48	28	97	
  B: 13		28	31	79	
  Y: 115	97	56	240	
  O: 102	88	48	236	
  W: 116	99	59	240	
  E: 22		19	18	39	

2 - Sensor 6:
  R: 94		64	38	145	
  G: 45		68	45	105	
  B: 49		57	48	102	
  Y: 123	107	71	233	
  O: 141	121	71	239	
  W: 124	107	61	236	
  E: 50		51	49	72	

2 - Sensor 7:
  R: 72		48	20	124	
  G: 27		51	27	84	
  B: 25		36	28	73	
  Y: 99		90	51	216	
  O: 105	94	48	222	
  W: 100	92	48	227	
  E: 38		39	40	59	

2 - Sensor 8:
  R: 94		66	28	164	
  G: 44		76	43	128	
  B: 46		58	43	115	
  Y: 133	126	72	231	
  O: 120	110	58	229	
  W: 131	130	69	231	
  E: 32		32	32	46

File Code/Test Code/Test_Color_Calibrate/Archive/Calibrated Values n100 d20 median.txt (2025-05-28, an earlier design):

Color Sensor 1
1 - Sensor 0:
  R: 105	84	19	174	
  G: 45		115	17	145	
  B: 40		68	21	88	
  Y: 163	196	24	241	
  O: 136	159	17	240	
  W: 167	205	19	242	
  E: 47		44	35	60	

1 - Sensor 1:
  R: 84		48	22	133	
  G: 24		67	34	111	
  B: 22		36	38	76	
  Y: 133	132	75	241	
  O: 115	107	56	239	
  W: 141	143	77	242	
  E: 28		28	22	42	

1 - Sensor 2:
  R: 108	62	32	146	
  G: 38		87	51	143	
  B: 40		56	57	108	
  Y: 176	157	95	220	
  O: 148	129	73	216	
  W: 185	168	94	219	
  E: 39		34	28	57	

1 - Sensor 3:
  R: 99		40	17	163	
  G: 27		73	44	150	
  B: 20		35	46	106	
  Y: 179	140	85	243	
  O: 146	110	63	241	
  W: 183	148	92	243	
  E: 41		45	34	68	

1 - Sensor 4:
  R: 86		46	13	157	
  G: 24		90	33	159	
  B: 16		46	33	105	
  Y: 150	158	64	243	
  O: 124	119	46	241	
  W: 157	173	71	243	
  E: 20		22	16	38	

1 - Sensor 5:
  R: 118	61	13	183	
  G: 28		91	35	147	
  B: 20		40	28	87	
  Y: 193	173	80	243	
  O: 166	156	64	243	
  W: 204	184	64	244	
  E: 52		49	36	86	

1 - Sensor 6:
  R: 69		45	14	143	
  G: 24		76	33	151	
  B: 19		43	31	108	
  Y: 126	139	68	243	
  O: 108	122	54	241	
  W: 135	154	68	243	
  E: 19		21	17	35	

1 - Sensor 7:
  R: 77		44	14	149	
  G: 26		80	36	158	
  B: 19		41	35	107	
  Y: 140	151	75	243	
  O: 124	128	60	242	
  W: 145	163	76	243	
  E: 15		16	12	31	

1 - Sensor 8:
  R: 67		38	8	124	
  G: 22		72	28	135	
  B: 16		34	26	87	
  Y: 125	134	59	242	
  O: 108	110	44	240	
  W: 136	149	62	243	
  E: 12		14	12	32	

Color Sensor 2
2 - Sensor 0:
  R: 73		38	7	118	
  G: 18		56	22	96	
  B: 14		24	17	56	
  Y: 124	113	56	240	
  O: 107	100	45	234	
  W: 128	114	43	240	
  E: 44		38	28	74	

2 - Sensor 1:
  R: 80		31	7	124	
  G: 24		47	20	98	
  B: 20		22	19	67	
  Y: 127	92	53	239	
  O: 112	78	40	230	
  W: 132	97	49	240	
  E: 31		22	18	55	

2 - Sensor 2:
  R: 67		0	7	76	
  G: 22		0	17	43	
  B: 16		0	19	38	
  Y: 107	0	46	158	
  O: 92		0	33	130	
  W: 116	0	51	173	
  E: 13		8	8	24	

2 - Sensor 3:
  R: 92		66	25	184	
  G: 26		82	40	152	
  B: 27		57	44	130	
  Y: 135	137	75	241	
  O: 122	123	63	240	
  W: 142	152	79	241	
  E: 36		35	30	73	

2 - Sensor 4:
  R: 65		40	14	127	
  G: 15		44	19	83	
  B: 14		27	19	66	
  Y: 101	83	39	231	
  O: 93		80	34	216	
  W: 103	92	39	236	
  E: 28		23	20	51	

2 - Sensor 5:
  R: 72		44	21	145	
  G: 19		59	35	120	
  B: 16		33	33	89	
  Y: 119	107	63	241	
  O: 103	88	49	237	
  W: 123	110	64	241	
  E: 17		14	14	35	

2 - Sensor 6:
  R: 113	78	45	174	
  G: 70		94	56	165	
  B: 69		72	55	140	
  Y: 159	141	87	240	
  O: 140	122	72	239	
  W: 163	141	78	241	
  E: 31		31	30	53	

2 - Sensor 7:
  R: 83		57	24	143	
  G: 39		67	31	120	
  B: 36		46	31	94	
  Y: 119	111	60	239	
  O: 104	94	49	221	
  W: 120	113	57	240	
  E: 25		27	27	46	

2 - Sensor 8:
  R: 104	74	31	179	
  G: 59		91	44	166	
  B: 54		60	43	124	
  Y: 142	136	73	231	
  O: 124	118	60	230	
  W: 148	142	71	232	
  E: 22		23	23	36

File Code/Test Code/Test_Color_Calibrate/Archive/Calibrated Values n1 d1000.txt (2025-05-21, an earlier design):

Color Sensor 1
1 - Sensor 0:
  R: 97		76	4	191	
  G: 41		33	4	79	
  B: 32		26	6	60	
  Y: 143	112	6	240	
  O: 119	92	3	232	
  W: 159	124	5	241	
  E: 30		26	19	43	

1 - Sensor 1:
  R: 78		44	15	139	
  G: 24		63	28	119	
  B: 15		26	25	64	
  Y: 115	109	54	240	
  O: 100	88	40	233	
  W: 135	134	65	242	
  E: 21		19	14	32	

1 - Sensor 2:
  R: 105	60	25	147	
  G: 43		89	44	173	
  B: 29		43	36	95	
  Y: 159	140	75	231	
  O: 128	108	54	149	
  W: 192	174	91	229	
  E: 39		33	27	56	

1 - Sensor 3:
  R: 105	43	23	179	
  G: 29		69	41	148	
  B: 21		32	38	98	
  Y: 179	134	73	243	
  O: 146	103	56	241	
  W: 187	144	83	243	
  E: 33		34	25	57	

1 - Sensor 4:
  R: 93		65	19	192	
  G: 28		93	32	168	
  B: 18		44	28	103	
  Y: 148	148	56	243	
  O: 130	127	45	242	
  W: 158	169	67	243	
  E: 18		18	14	33	

1 - Sensor 5:
  R: 120	66	15	192	
  G: 28		89	33	147	
  B: 20		38	25	82	
  Y: 187	163	72	243	
  O: 163	151	60	243	
  W: 203	180	62	244	
  E: 49		46	33	82	

1 - Sensor 6:
  R: 80		61	19	180	
  G: 29		81	33	162	
  B: 24		43	30	115	
  Y: 129	135	63	243	
  O: 111	119	51	241	
  W: 142	154	63	243	
  E: 20		21	17	35	

1 - Sensor 7:
  R: 87		60	19	183	
  G: 28		81	35	161	
  B: 24		42	32	112	
  Y: 140	145	70	243	
  O: 122	123	55	242	
  W: 148	165	75	243	
  E: 13		14	11	28	

1 - Sensor 8:
  R: 75		46	11	146	
  G: 26		71	27	139	
  B: 19		33	23	85	
  Y: 127	130	55	242	
  O: 110	107	41	240	
  W: 140	152	62	243	
  E: 9		12	9	29	

Color Sensor 2
2 - Sensor 0:
  R: 71		35	7	113	
  G: 15		49	19	84	
  B: 15		25	17	60	
  Y: 121	109	54	240	
  O: 100	93	41	224	
  W: 127	113	41	240	
  E: 40		33	24	69	

2 - Sensor 1:
  R: 73		27	6	113	
  G: 15		39	19	79	
  B: 20		23	20	70	
  Y: 121	88	50	238	
  O: 103	72	38	216	
  W: 125	92	46	239	
  E: 27		19	15	50	

2 - Sensor 2:
  R: 62		0	5	71	
  G: 15		0	16	33	
  B: 18		0	21	42	
  Y: 99		0	42	147	
  O: 85		0	31	122	
  W: 113	0	47	167	
  E: 11		6	6	22	

2 - Sensor 3:
  R: 81		55	19	160	
  G: 18		67	31	120	
  B: 17		44	40	105	
  Y: 124	120	65	240	
  O: 118	115	56	240	
  W: 131	135	70	241	
  E: 32		31	25	67	

2 - Sensor 4:
  R: 60		34	11	113	
  G: 11		35	14	65	
  B: 8		21	17	52	
  Y: 94		74	34	214	
  O: 88		73	31	202	
  W: 95		79	33	221	
  E: 23		18	15	45	

2 - Sensor 5:
  R: 65		36	17	128	
  G: 15		49	29	100	
  B: 12		26	32	76	
  Y: 113	96	55	240	
  O: 100	84	47	236	
  W: 115	98	57	240	
  E: 14		12	10	31	

2 - Sensor 6:
  R: 80		48	20	135	
  G: 29		52	27	92	
  B: 29		37	29	80	
  Y: 102	86	49	216	
  O: 119	99	50	236	
  W: 111	92	45	233	
  E: 25		25	24	46	

2 - Sensor 7:
  R: 66		41	11	120	
  G: 17		42	18	75	
  B: 17		28	19	63	
  Y: 88		78	40	206	
  O: 90		79	35	204	
  W: 91		83	39	219	
  E: 18		19	19	38	

2 - Sensor 8:
  R: 83		54	16	152	
  G: 31		63	29	116	
  B: 31		45	30	102	
  Y: 116	110	56	231	
  O: 102	96	44	228	
  W: 120	119	55	231	
  E: 15		15	15	28

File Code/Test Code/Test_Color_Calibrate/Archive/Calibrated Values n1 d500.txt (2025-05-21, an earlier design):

Color Sensor 1
1 - Sensor 0:
  R: 90		69	0	184	
  G: 31		24	0	65	
  B: 17		12	0	35	
  Y: 133	102	0	239	
  O: 119	92	0	234	
  W: 147	115	0	240	
  E: 11		7	0	22	

1 - Sensor 1:
  R: 75		40	11	136	
  G: 15		56	24	106	
  B: 7		20	23	57	
  Y: 115	112	57	241	
  O: 105	97	46	239	
  W: 129	130	65	242	
  E: 8		7	1	21	

1 - Sensor 2:
  R: 99		54	19	182	
  G: 28		76	38	150	
  B: 13		28	27	74	
  Y: 148	128	68	222	
  O: 140	121	65	216	
  W: 176	163	81	219	
  E: 17		12	7	35	

1 - Sensor 3:
  R: 105	43	25	181	
  G: 30		73	45	156	
  B: 19		34	42	102	
  Y: 179	140	80	243	
  O: 147	110	67	241	
  W: 183	147	92	243	
  E: 13		13	6	37	

1 - Sensor 4:
  R: 94		64	19	191	
  G: 25		92	33	164	
  B: 16		41	30	99	
  Y: 148	151	62	243	
  O: 132	135	52	242	
  W: 158	178	73	243	
  E: 6		8	3	23	

1 - Sensor 5:
  R: 122	67	15	196	
  G: 27	90	35	147	
  B: 19	37	25	82	
  Y: 188	166	76	243	
  O: 171	163	69	243	
  W: 203	184	64	243	
  E: 27	24	11	61	

1 - Sensor 6:
  R: 80		63	21	183	
  G: 30		83	35	166	
  B: 23		44	33	115	
  Y: 128	139	68	242	
  O: 110	124	56	241	
  W: 136	164	71	243	
  E: 6		6	3	20	

1 - Sensor 7:
  R: 87		61	21	184	
  G: 25		80	35	155	
  B: 22		42	35	112	
  Y: 140	148	75	243	
  O: 120	131	64	242	
  W: 148	174	81	243	
  E: 6		7	3	20	

1 - Sensor 8:
  R: 77		48	12	150	
  G: 23		72	28	137	
  B: 17		33	24	86	
  Y: 129	135	60	242	
  O: 108	112	48	240	
  W: 140	158	66	243	
  E: 7		9	7	27	

Color Sensor 2
2 - Sensor 0:
  R: 70		35	7	113	
  G: 15		49	19	84	
  B: 14		25	19	60	
  Y: 120	108	55	240	
  O: 102	96	44	230	
  W: 124	112	41	239	
  E: 26		19	9	56	

2 - Sensor 1:
  R: 73		28	7	114	
  G: 16		41	19	83	
  B: 22		24	22	72	
  Y: 124	90	54	239	
  O: 105	75	41	223	
  W: 127	96	49	239	
  E: 19		12	7	44	

2 - Sensor 2:
  R: 62		0	7	71	
  G: 14		0	17	35	
  B: 19		0	22	44	
  Y: 105	0	48	159	
  O: 88		0	33	128	
  W: 115	0	52	173	
  E: 7		3	4	19	

2 - Sensor 3:
  R: 83		59	22	167	
  G: 21		73	34	133	
  B: 23		56	46	129	
  Y: 132	132	71	240	
  O: 121	124	62	240	
  W: 135	147	77	241	
  E: 20		19	14	56	

2 - Sensor 4:
  R: 60		33	12	113	
  G: 11		36	15	68	
  B: 12		27	19	65	
  Y: 99		81	38	228	
  O: 90		79	35	214	
  W: 97		84	37	230	
  E: 15		11	8	38	

2 - Sensor 5:
  R: 66		36	18	129	
  G: 15		52	32	107	
  B: 15		32	35	89	
  Y: 114	100	62	240	
  O: 103	88	49	237	
  W: 116	102	62	240	
  E: 9		6	7	27	

2 - Sensor 6:
  R: 70		38	9	125	
  G: 27		51	19	104	
  B: 31		37	23	100	
  Y: 107	88	43	236	
  O: 107	89	39	235	
  W: 114	96	41	239	
  E: 9		10	8	31	

2 - Sensor 7:
  R: 58		34	7	109	
  G: 17		43	15	85	
  B: 22		32	18	81	
  Y: 90		83	38	225	
  O: 80		74	30	201	
  W: 91		87	38	231	
  E: 7		8	8	26	

2 - Sensor 8:
  R: 75		48	11	146	
  G: 27		63	24	126	
  B: 32		41	23	107	
  Y: 113	112	52	238	
  O: 100	95	39	235	
  W: 121	120	52	239	
  E: 4		5	5	18

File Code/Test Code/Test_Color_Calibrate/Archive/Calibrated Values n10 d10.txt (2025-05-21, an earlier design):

Color Sensor 1
1 - Sensor 0:
  R: 83		69	0	161	
  G: 29		99	0	135	
  B: 16		41	0	63	
  Y: 130	162	0	240	
  O: 116	140	0	239	
  W: 145	190	0	241	
  E: 10		7	0	22	

1 - Sensor 1:
  R: 71		36	8	127	
  G: 15		56	23	103	
  B: 7		19	22	55	
  Y: 113	112	55	240	
  O: 98		90	39	235	
  W: 125	128	62	241	
  E: 7		7	1	20	

1 - Sensor 2:
  R: 94		48	16	165	
  G: 24		72	33	139	
  B: 13		28	27	75	
  Y: 146	127	66	221	
  O: 128	110	50	204	
  W: 169	154	76	216	
  E: 16		11	6	34	

1 - Sensor 3:
  R: 99		40	21	167	
  G: 31		74	42	155	
  B: 18		33	42	101	
  Y: 176	139	79	243	
  O: 147	108	57	241	
  W: 180	145	90	243	
  E: 12		15	5	39	

1 - Sensor 4:
  R: 87		49	14	164	
  G: 25		92	32	163	
  B: 18		45	30	103	
  Y: 147	153	62	243	
  O: 128	125	45	241	
  W: 154	172	70	243	
  E: 7		8	3	23	

1 - Sensor 5:
  R: 116	60	12	182	
  G: 28		92	34	151	
  B: 19		38	25	83	
  Y: 187	166	75	243	
  O: 163	155	63	243	
  W: 200	181	62	243	
  E: 27		24	10	61	

1 - Sensor 6:
  R: 69		49	16	151	
  G: 32		85	35	172	
  B: 24		47	33	120	
  Y: 127	139	66	242	
  O: 110	119	52	241	
  W: 134	158	68	243	
  E: 5		6	3	19	

1 - Sensor 7:
  R: 79		50	16	160	
  G: 27		83	37	163	
  B: 25		46	35	120	
  Y: 137	148	75	243	
  O: 122	129	60	241	
  W: 144	163	76	243	
  E: 6	6	3	20	

1 - Sensor 8:
  R: 67		39	9	128	
  G: 24		73	28	139	
  B: 19		36	26	93	
  Y: 128	135	58	242	
  O: 109	110	43	240	
  W: 137	152	62	243	
  E: 7		8	6	27

Color Sensor 2
2 - Sensor 0:
  R: 69		34	6	110	
  G: 15		51	20	88	
  B: 14		25	17	59	
  Y: 117	105	53	239	
  O: 101	96	44	228	
  W: 120	107	40	238	
  E: 25		19	9	56	

2 - Sensor 1:
  R: 71		27	6	111	
  G: 16		41	19	83	
  B: 21		24	21	72	
  Y: 120	88	53	238	
  O: 104	75	40	222	
  W: 123	92	48	239	
  E: 19	11	7	43	

2 - Sensor 2:
  R: 60		0	6	69	
  G: 15		0	17	36	
  B: 16		0	20	40	
  Y: 104	0	50	160	
  O: 87		0	33	126	
  W: 113	0	52	172	
  E: 7		3	3	19	

2 - Sensor 3:
  R: 75		50	19	149	
  G: 19		71	35	131	
  B: 19		52	44	121	
  Y: 120	118	63	240	
  O: 122	124	63	240	
  W: 131	140	73	241	
  E: 19		19	13	56	

2 - Sensor 4:
  R: 55	26	9	97	
  G: 11	36	15	69	
  B: 10	25	19	60	
  Y: 92	71	34	209	
  O: 89	76	33	209	
  W: 95	79	34	221	
  E: 14	10	7	37	

2 - Sensor 5:
  R: 62		31	17	119	
  G: 15		52	31	107	
  B: 14		31	33	86	
  Y: 106	88	56	239	
  O: 103	87	48	237	
  W: 113	99	62	240	
  E: 9		6	6	27	

2 - Sensor 6:
  R: 57		28	7	99	
  G: 27		52	20	108	
  B: 29		36	22	96	
  Y: 93		77	38	216	
  O: 102	85	38	230	
  W: 112	94	40	238	
  E: 9		9	8	31	

2 - Sensor 7:
  R: 49		27	5	89	
  G: 16		44	15	84	
  B: 20		31	18	79	
  Y: 77		71	33	197	
  O: 81		72	29	199	
  W: 89		85	36	228	
  E: 6		7	8	25	

Sensor 8:
  R: 68		43	10	133	
  G: 28		63	23	127	
  B: 30		39	22	101	
  Y: 103	104	49	237	
  O: 96		91	37	232	
  W: 118	119	52	239	
  E: 4		5	5	18

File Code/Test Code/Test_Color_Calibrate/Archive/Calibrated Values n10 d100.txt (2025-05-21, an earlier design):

Color Sensor 1
1 - Sensor 0:
  R: 87		67	0	178	
  G: 25		19	0	52	
  B: 22		16	0	47	
  Y: 140	108	0	240	
  O: 115	89	0	231	
  W: 143	111	0	240	
  E: 10		7	0	22	

1 - Sensor 1:
  R: 73		38	10	131	
  G: 11		49	20	89	
  B: 11		26	26	71	
  Y: 120	120	61	241	
  O: 100	91	42	236	
  W: 122	120	59	241	
  E: 8		6	1	20	

1 - Sensor 2:
  R: 98		51	19	176	
  G: 18		63	27	116	
  B: 20		38	39	107	
  Y: 162	145	79	222	
  O: 128	110	54	200	
  W: 162	142	68	220	
  E: 16		11	6	34	

1 - Sensor 3:
  R: 102	44	23	176	
  G: 25		70	37	140	
  B: 19		34	48	108	
  Y: 178	138	85	243	
  O: 146	105	59	241	
  W: 183	147	87	243	
  E: 12		13	6	37	

1 - Sensor 4:
  R: 91		55	16	175	
  G: 19		77	26	135	
  B: 17		51	36	116	
  Y: 151	160	67	243	
  O: 123	117	44	241	
  W: 151	159	65	243	
  E: 7		7	3	23	

1 - Sensor 5:
  R: 120	63	13	189	
  G: 24		83	31	135	
  B: 19		40	29	88	
  Y: 192	171	79	243	
  O: 163	152	63	243	
  W: 196	173	59	243	
  E: 27		23	11	61	

1 - Sensor 6:
  R: 76		56	18	169	
  G: 28		78	32	157	
  B: 23		48	34	121	
  Y: 127	148	71	243	
  O: 112	126	56	241	
  W: 136	152	67	243	
  E: 5		6	3	19	

1 - Sensor 7:
  R: 86		56	19	175	
  G: 27		78	35	155	
  B: 24		49	39	126	
  Y: 141	159	79	243	
  O: 125	135	64	242	
  W: 146	157	74	243	
  E: 6	6	3	20	

1 - Sensor 8:
  R: 73		44	11	142	
  G: 23		68	25	129	
  B: 20		39	30	101	
  Y: 131	141	63	242	
  O: 111	114	48	240	
  W: 135	146	59	242	
  E: 6		8	7	28	

Color Sensor 2
2 - Sensor 0:
  R: 71		35	7	114	
  G: 19		58	22	99	
  B: 11		20	16	51	
  Y: 115	103	51	238	
  O: 97		91	41	219	
  W: 125	113	43	240	
  E: 25		19	9	56	

2 - Sensor 1:
  R: 74		28	7	114	
  G: 24		48	22	101	
  B: 13		18	19	56	
  Y: 119	88	51	238	
  O: 103	75	39	220	
  W: 128	96	51	239	
  E: 19		11	7	43	

2 - Sensor 2:
  R: 60		0	5	68	
  G: 22		0	20	46	
  B: 12		0	19	33	
  Y: 103	0	47	156	
  O: 89		0	33	128	
  W: 112	0	52	171	
  E: 7		3	3	19	

2 - Sensor 3:
  R: 86		60	23	174	
  G: 23		82	44	153	
  B: 19		46	39	108	
  Y: 127	129	69	240	
  O: 116	114	57	239	
  W: 140	148	78	241	
  E: 19		19	14	56	

2 - Sensor 4:
  R: 63		34	11	116	
  G: 12		40	18	78	
  B: 9		21	17	54	
  Y: 93		77	36	218	
  O: 85		72	32	200	
  W: 103	88	38	236	
  E: 14		10	7	37	

2 - Sensor 5:
  R: 71		41	18	139	
  G: 15		51	32	107	
  B: 14		32	34	88	
  Y: 107	91	56	239	
  O: 96		81	45	230	
  W: 123	112	68	241	
  E: 9		6	6	27	

2 - Sensor 6:
  R: 71		37	9	125	
  G: 29		55	22	115	
  B: 22		28	19	76	
  Y: 100	83	39	230	
  O: 100	82	35	223	
  W: 119	100	43	239	
  E: 9		9	8	31	

2 - Sensor 7:
  R: 59		33	7	109	
  G: 20		48	17	96	
  B: 14		25	16	63	
  Y: 82		77	33	208	
  O: 74		67	27	183	
  W: 96		91	41	236	
  E: 6		7	7	26	

2 - Sensor 8:
  R: 75		45	9	140	
  G: 33		66	25	136	
  B: 24		36	22	92	
  Y: 109	108	49	238	
  O: 95		91	38	232	
  W: 121	122	55	239	
  E: 4		5	5	18

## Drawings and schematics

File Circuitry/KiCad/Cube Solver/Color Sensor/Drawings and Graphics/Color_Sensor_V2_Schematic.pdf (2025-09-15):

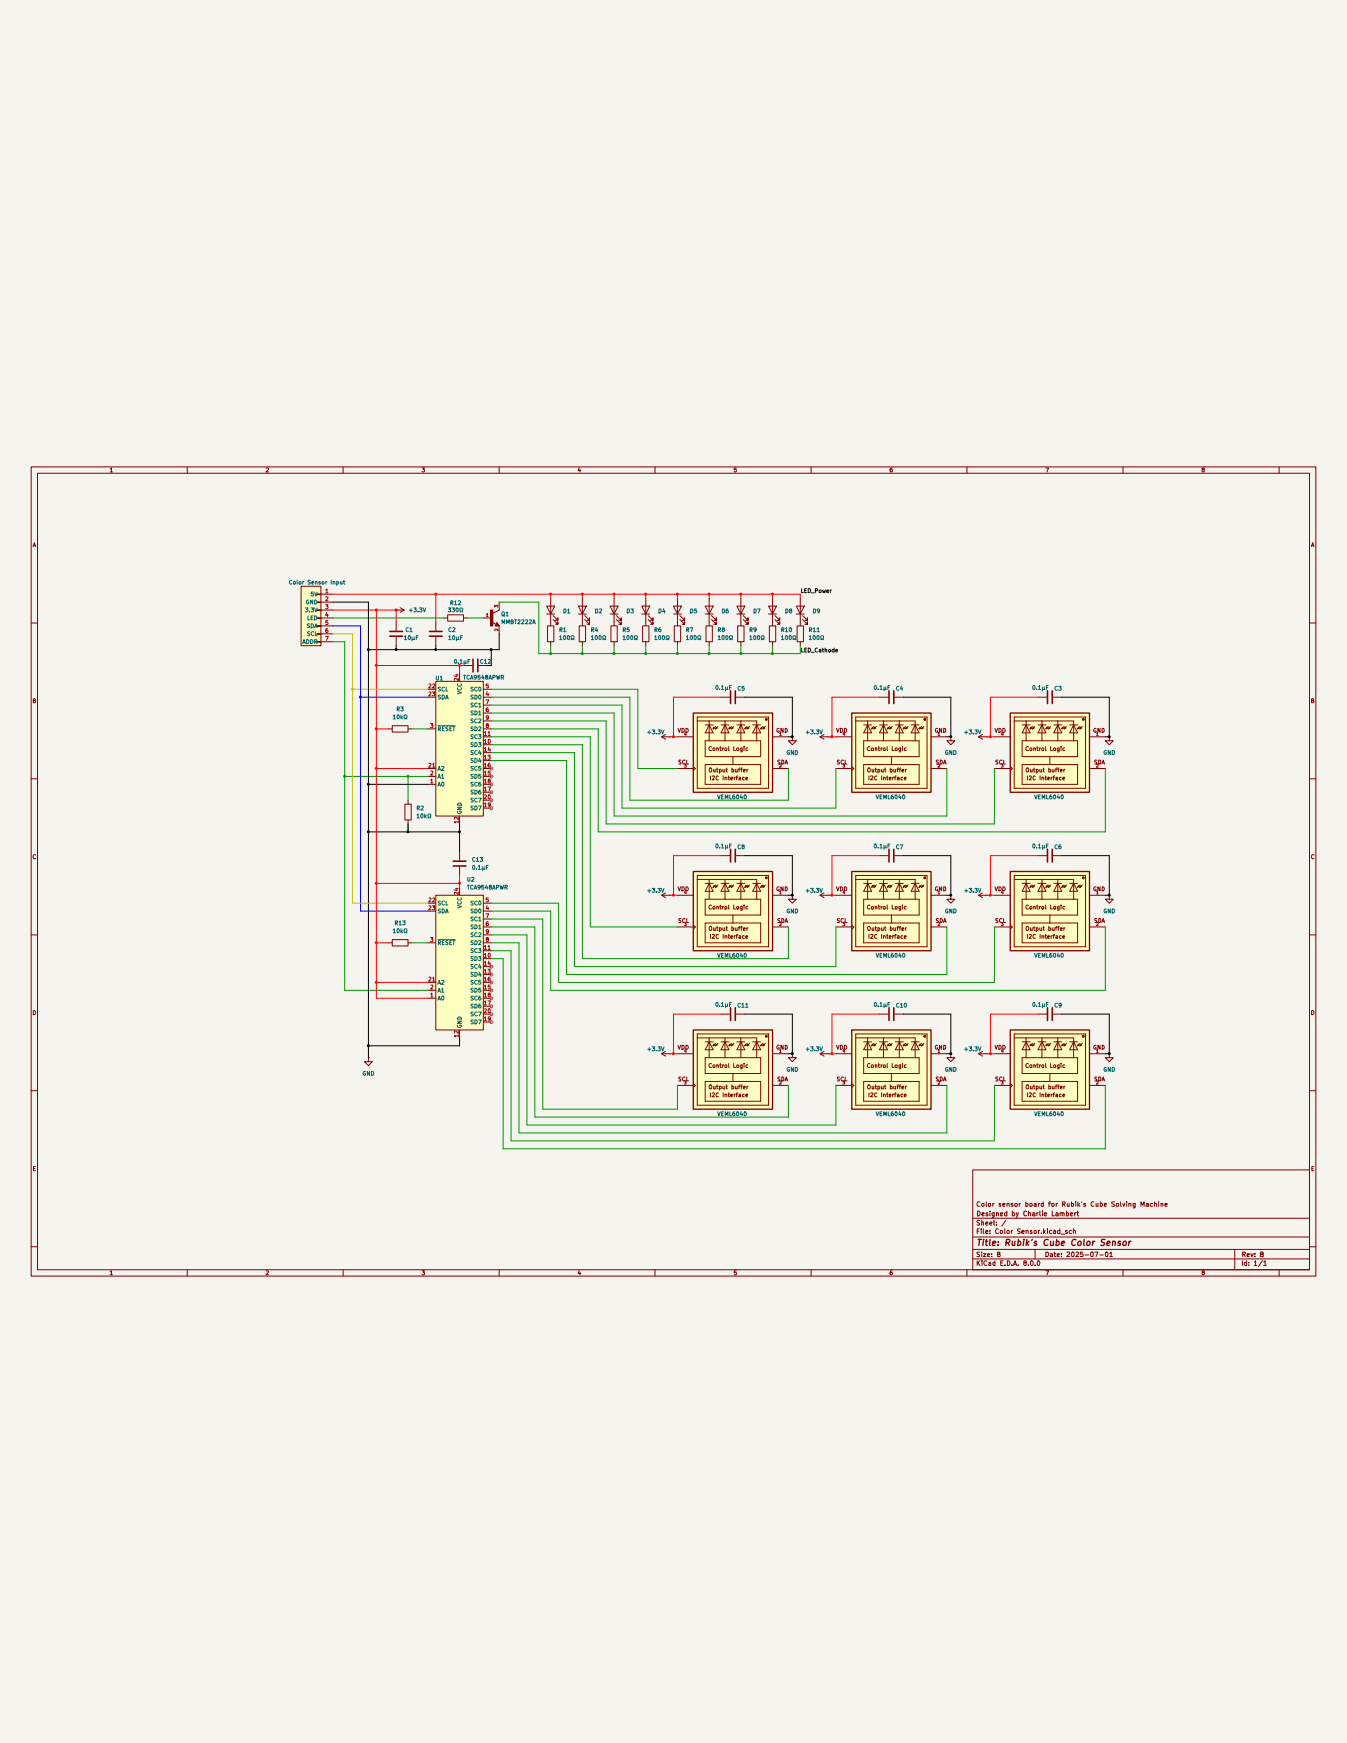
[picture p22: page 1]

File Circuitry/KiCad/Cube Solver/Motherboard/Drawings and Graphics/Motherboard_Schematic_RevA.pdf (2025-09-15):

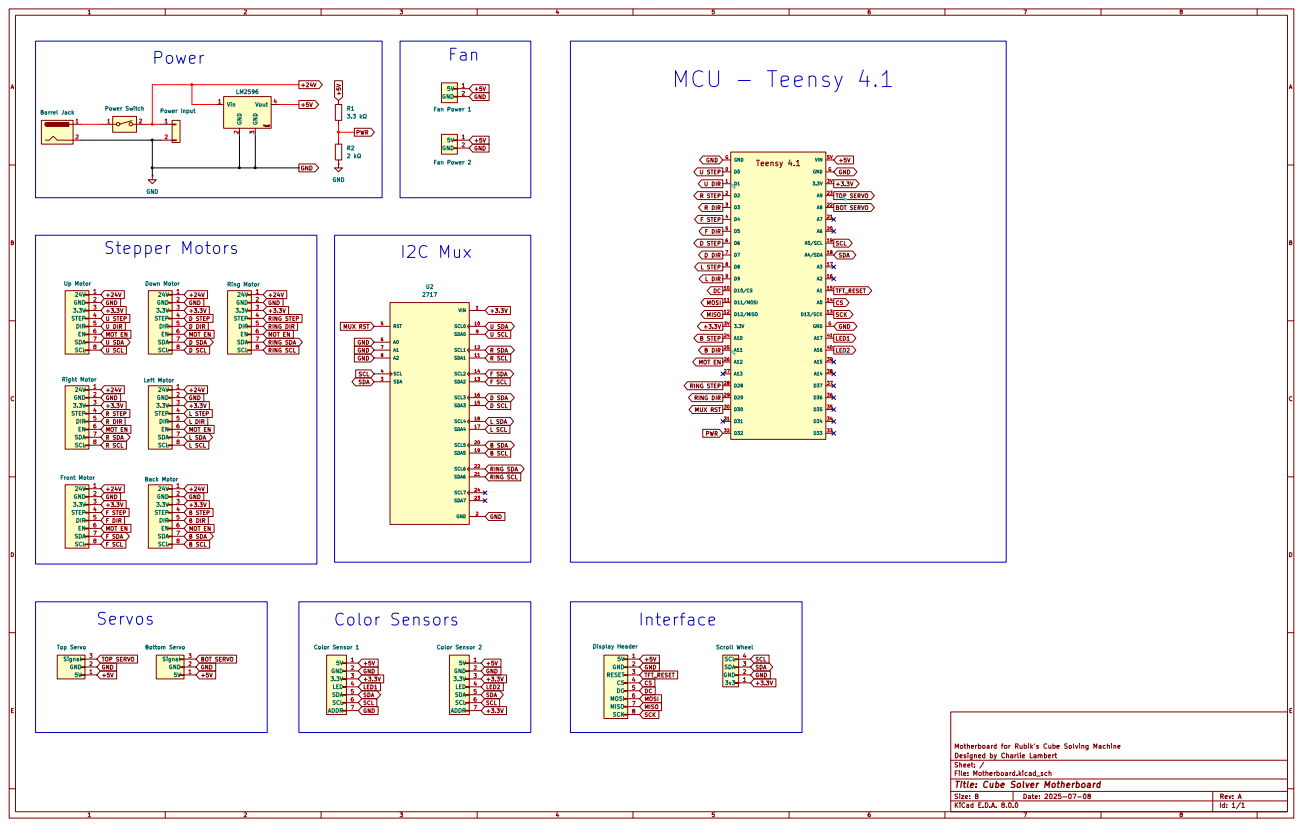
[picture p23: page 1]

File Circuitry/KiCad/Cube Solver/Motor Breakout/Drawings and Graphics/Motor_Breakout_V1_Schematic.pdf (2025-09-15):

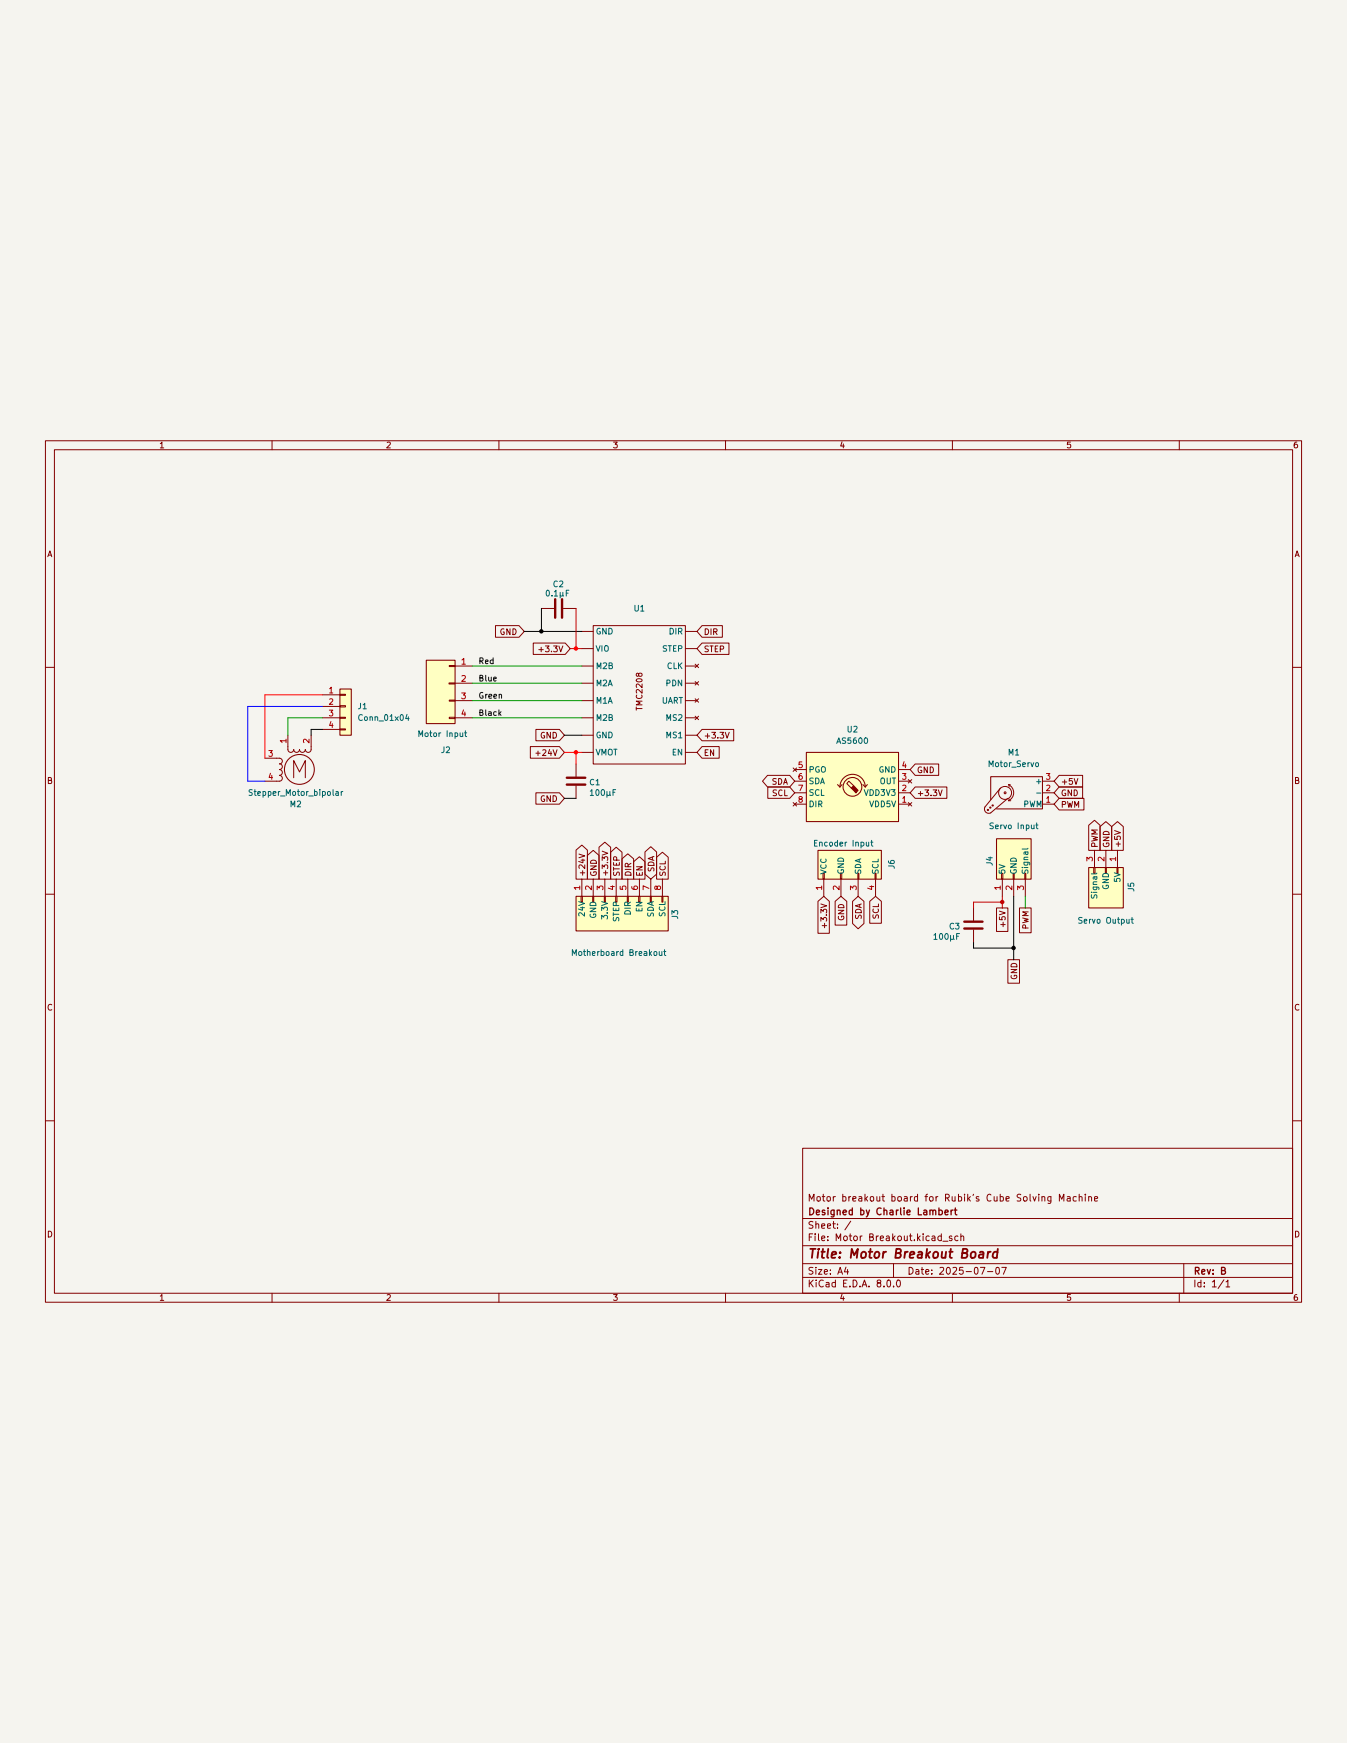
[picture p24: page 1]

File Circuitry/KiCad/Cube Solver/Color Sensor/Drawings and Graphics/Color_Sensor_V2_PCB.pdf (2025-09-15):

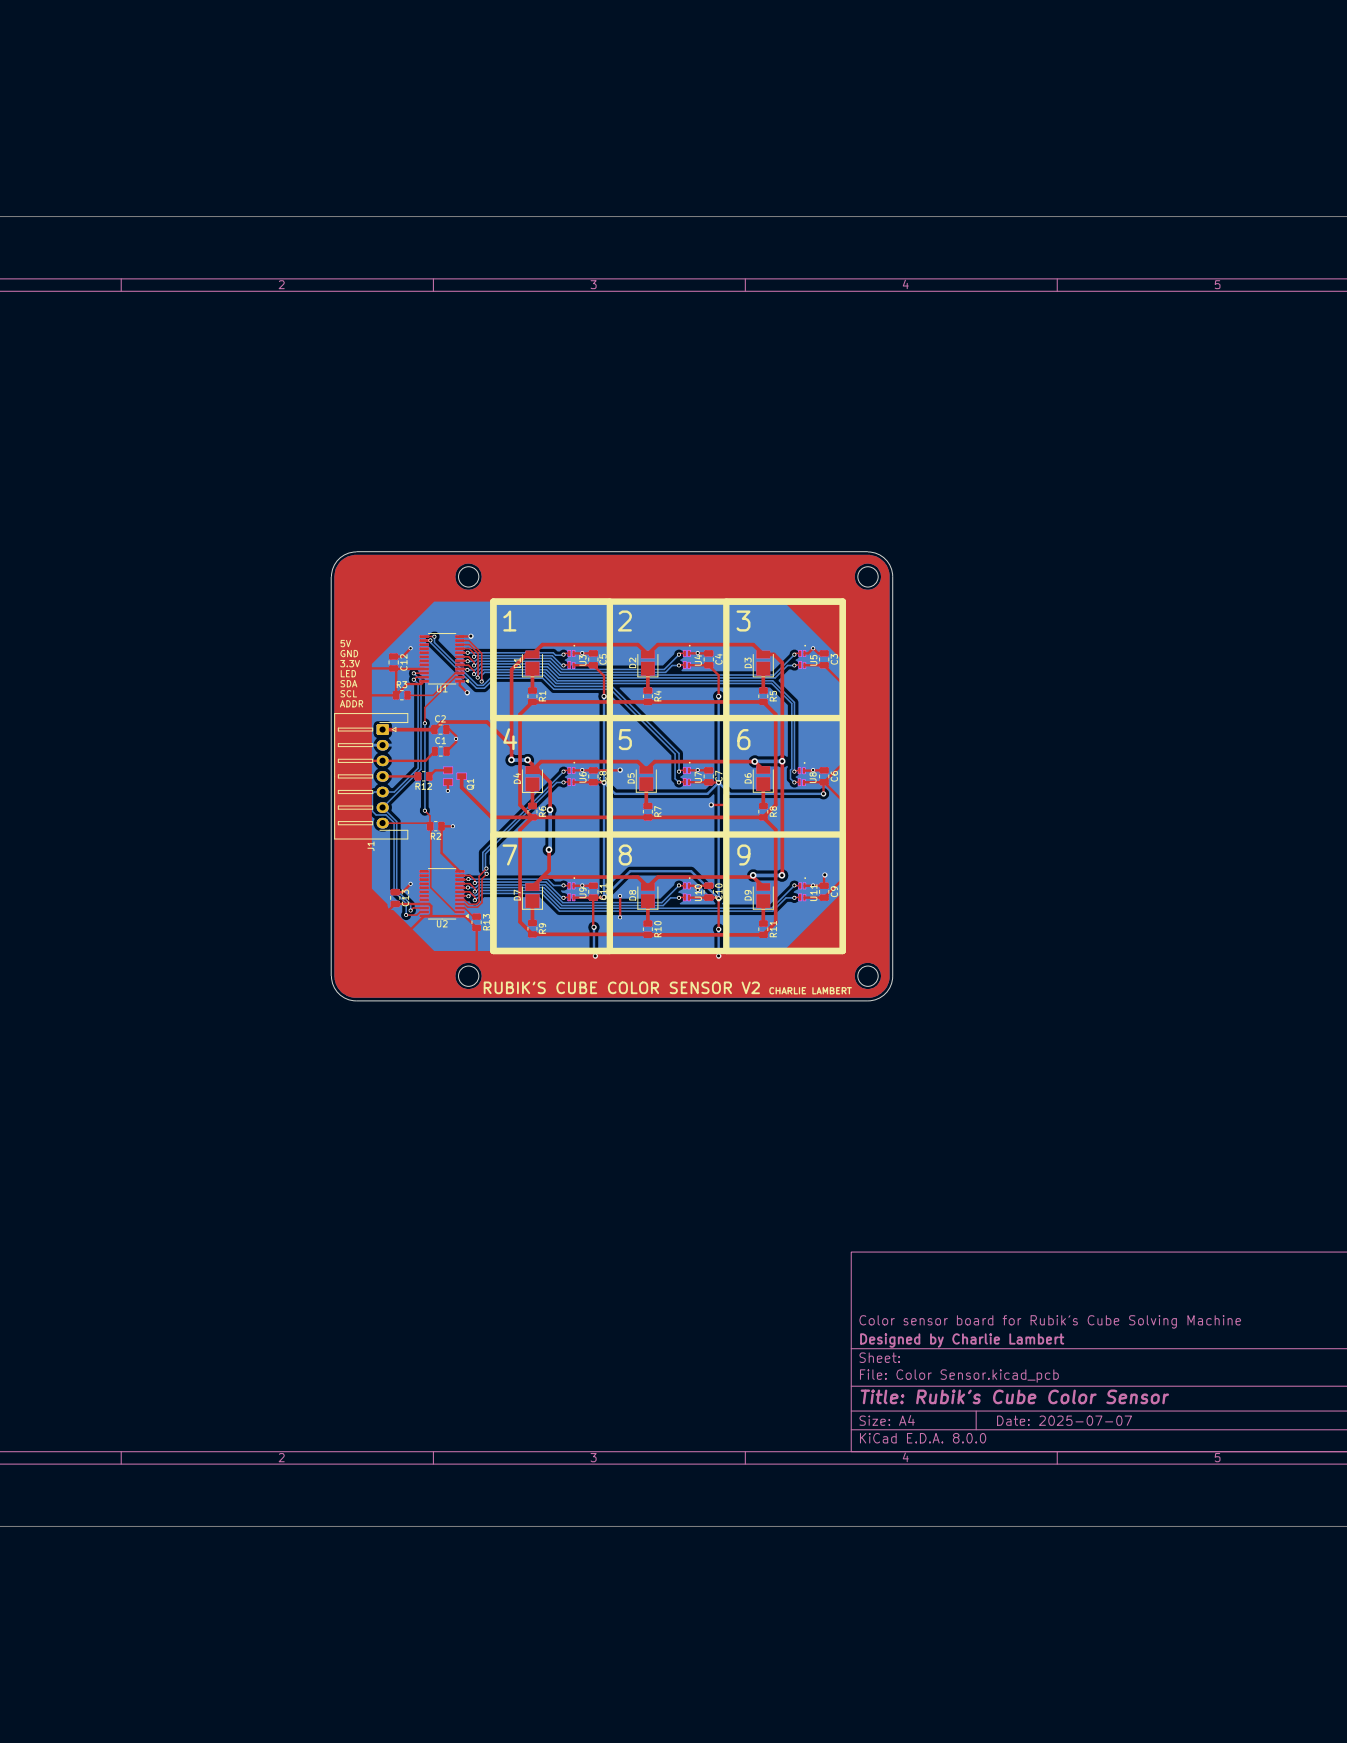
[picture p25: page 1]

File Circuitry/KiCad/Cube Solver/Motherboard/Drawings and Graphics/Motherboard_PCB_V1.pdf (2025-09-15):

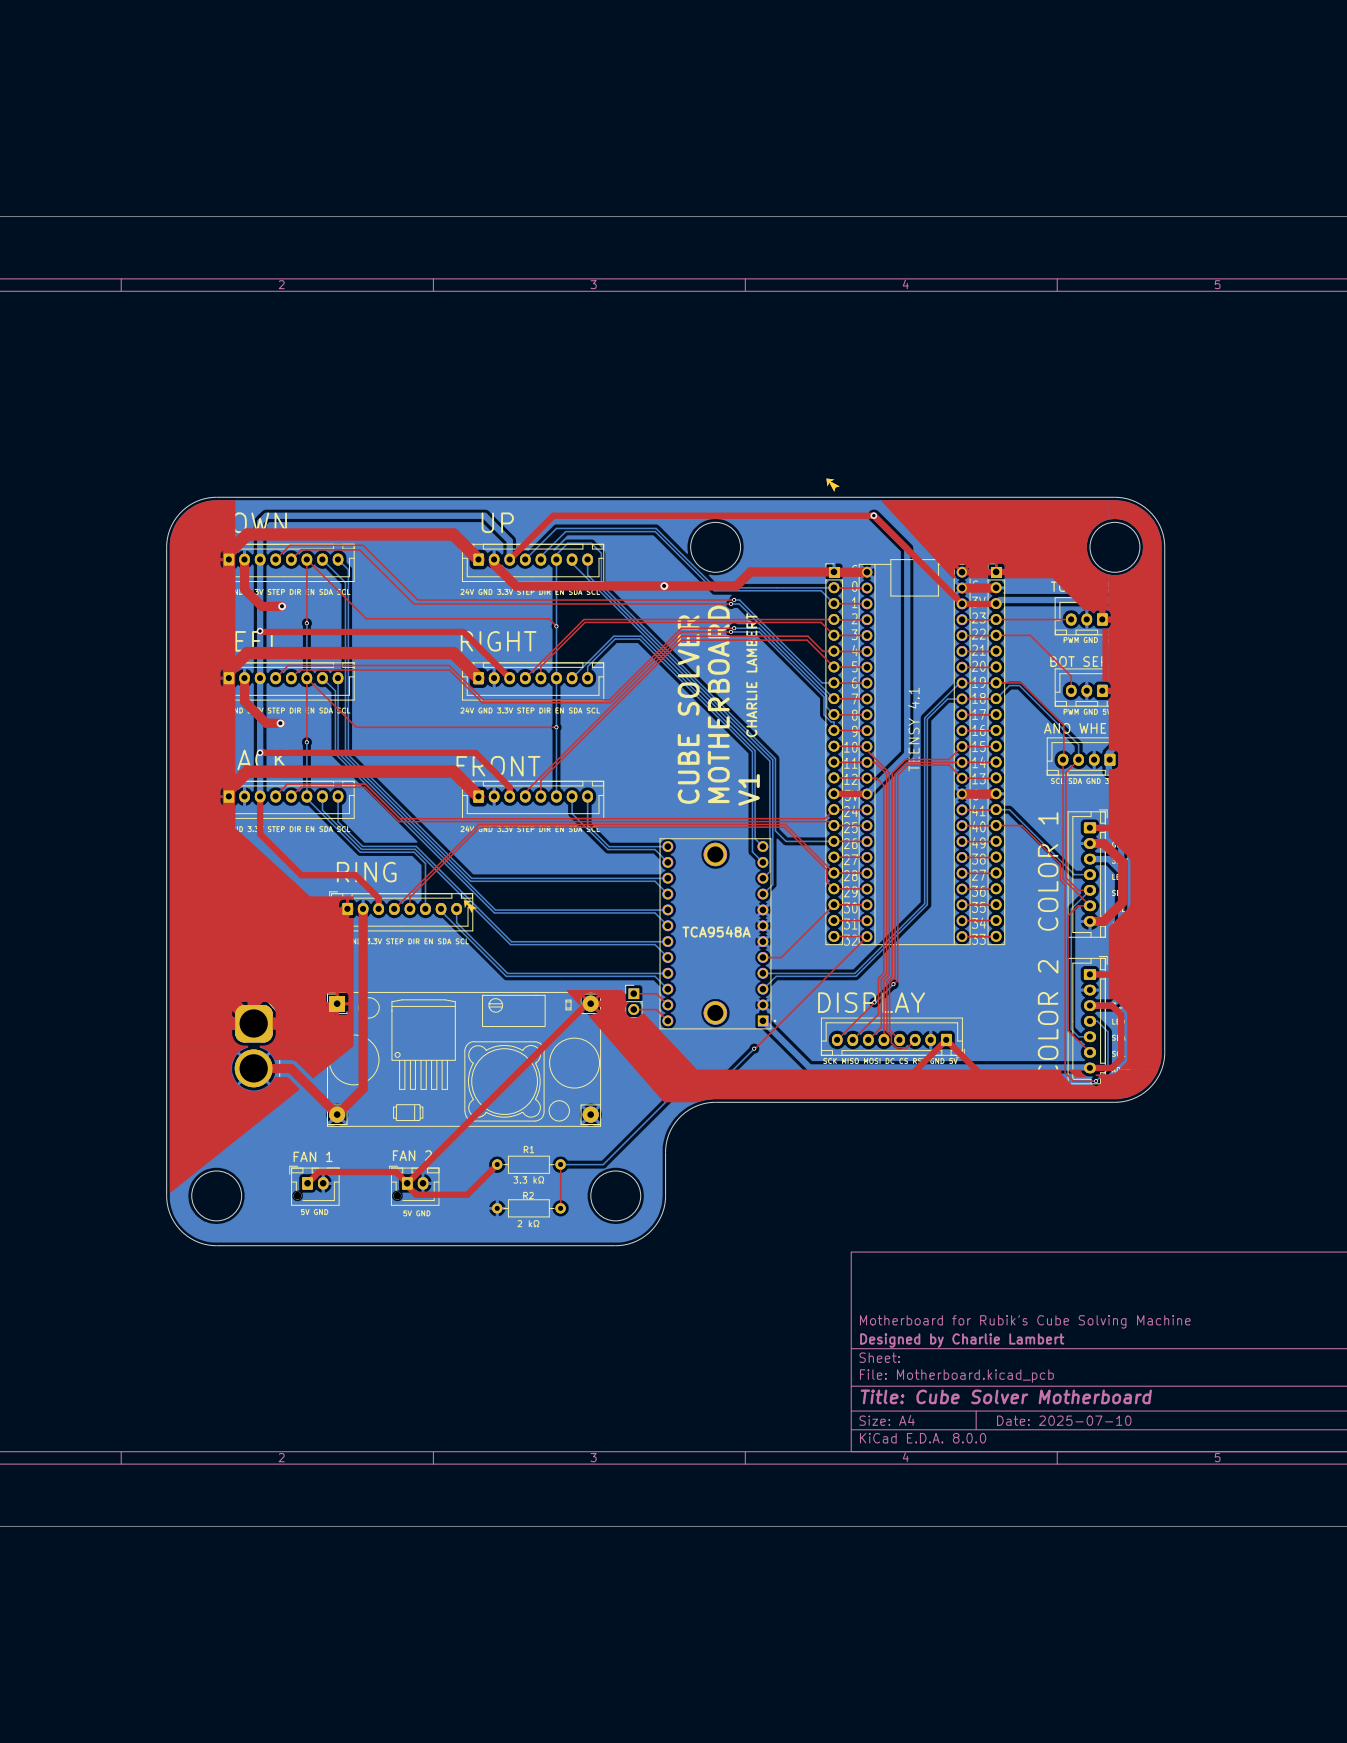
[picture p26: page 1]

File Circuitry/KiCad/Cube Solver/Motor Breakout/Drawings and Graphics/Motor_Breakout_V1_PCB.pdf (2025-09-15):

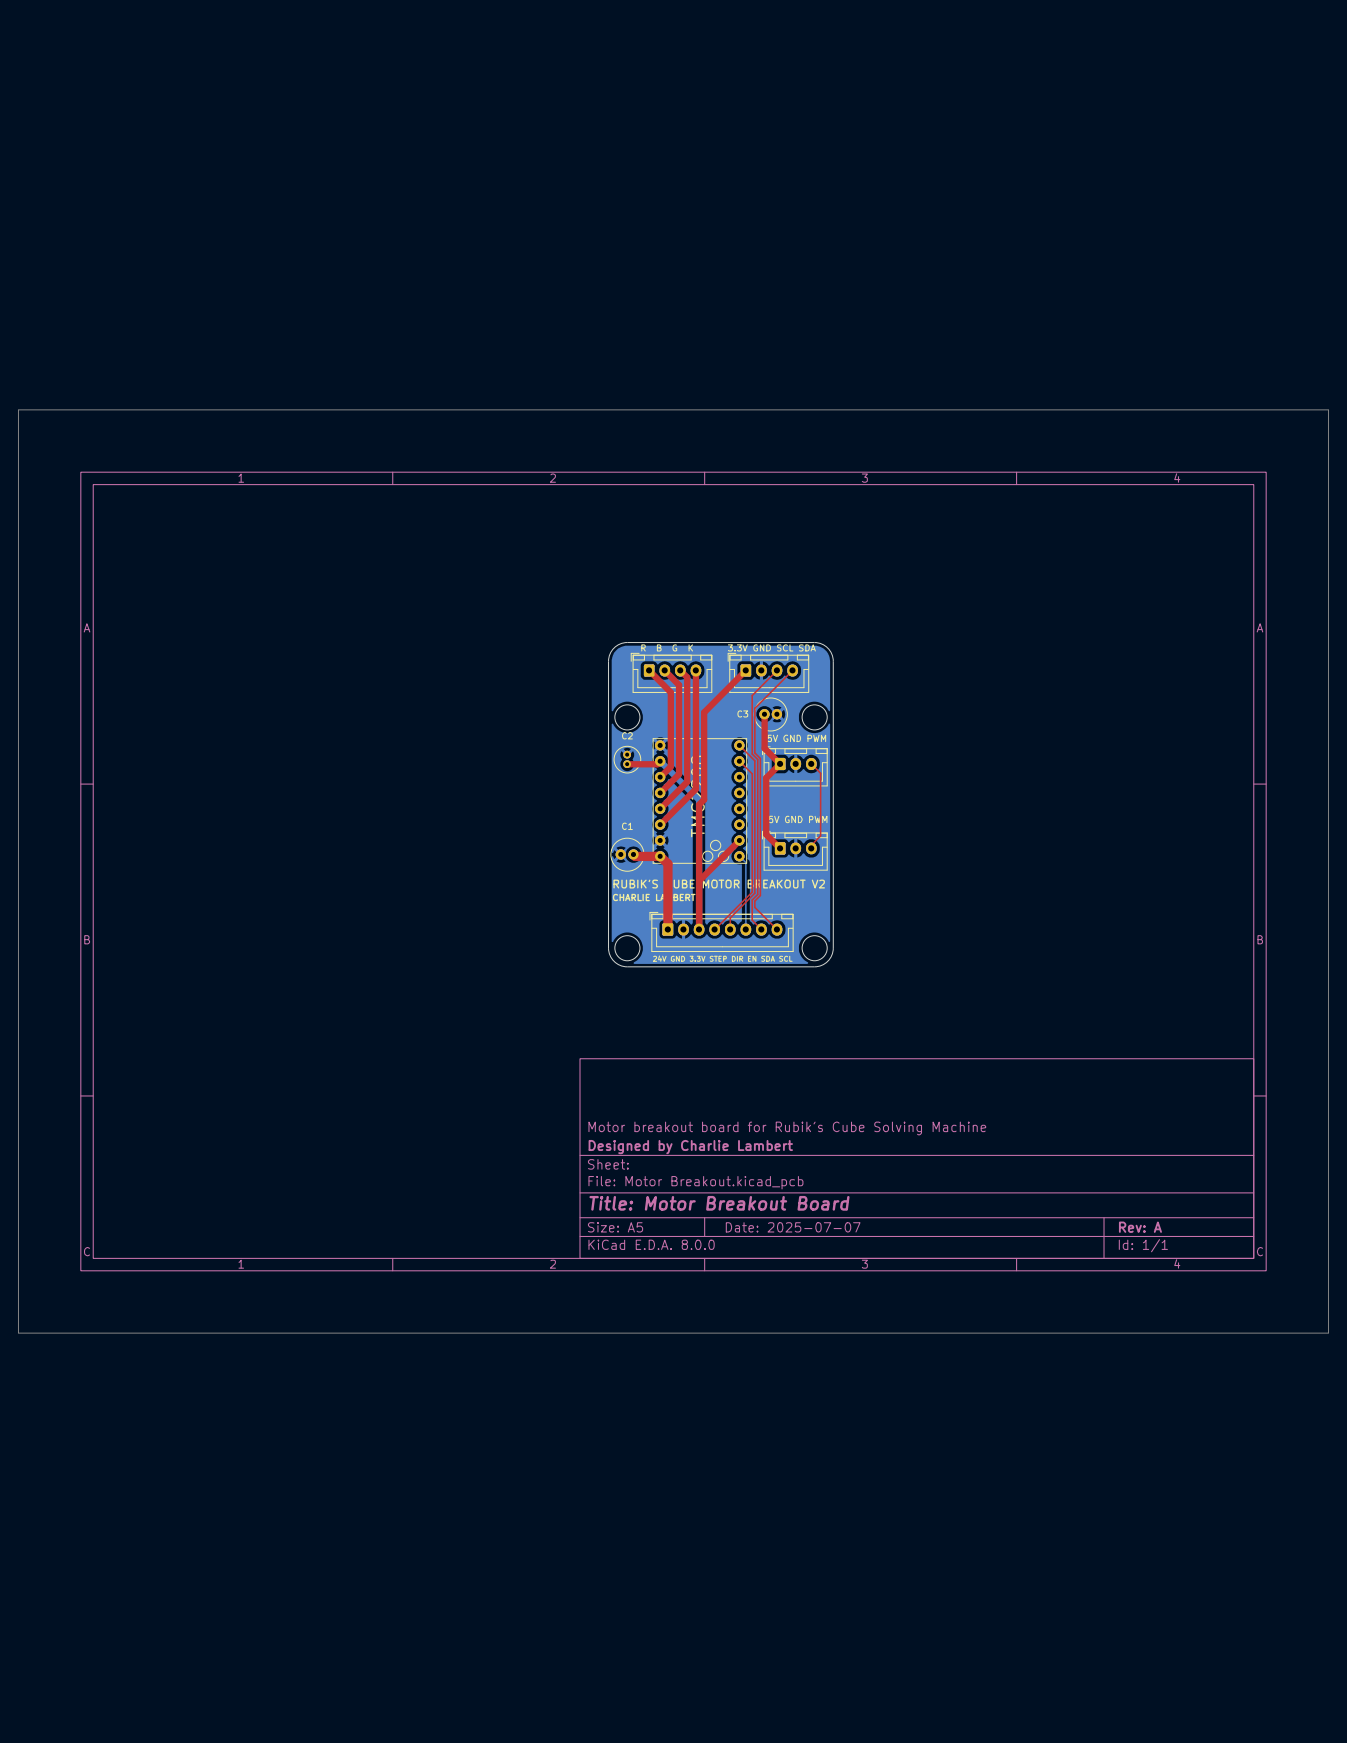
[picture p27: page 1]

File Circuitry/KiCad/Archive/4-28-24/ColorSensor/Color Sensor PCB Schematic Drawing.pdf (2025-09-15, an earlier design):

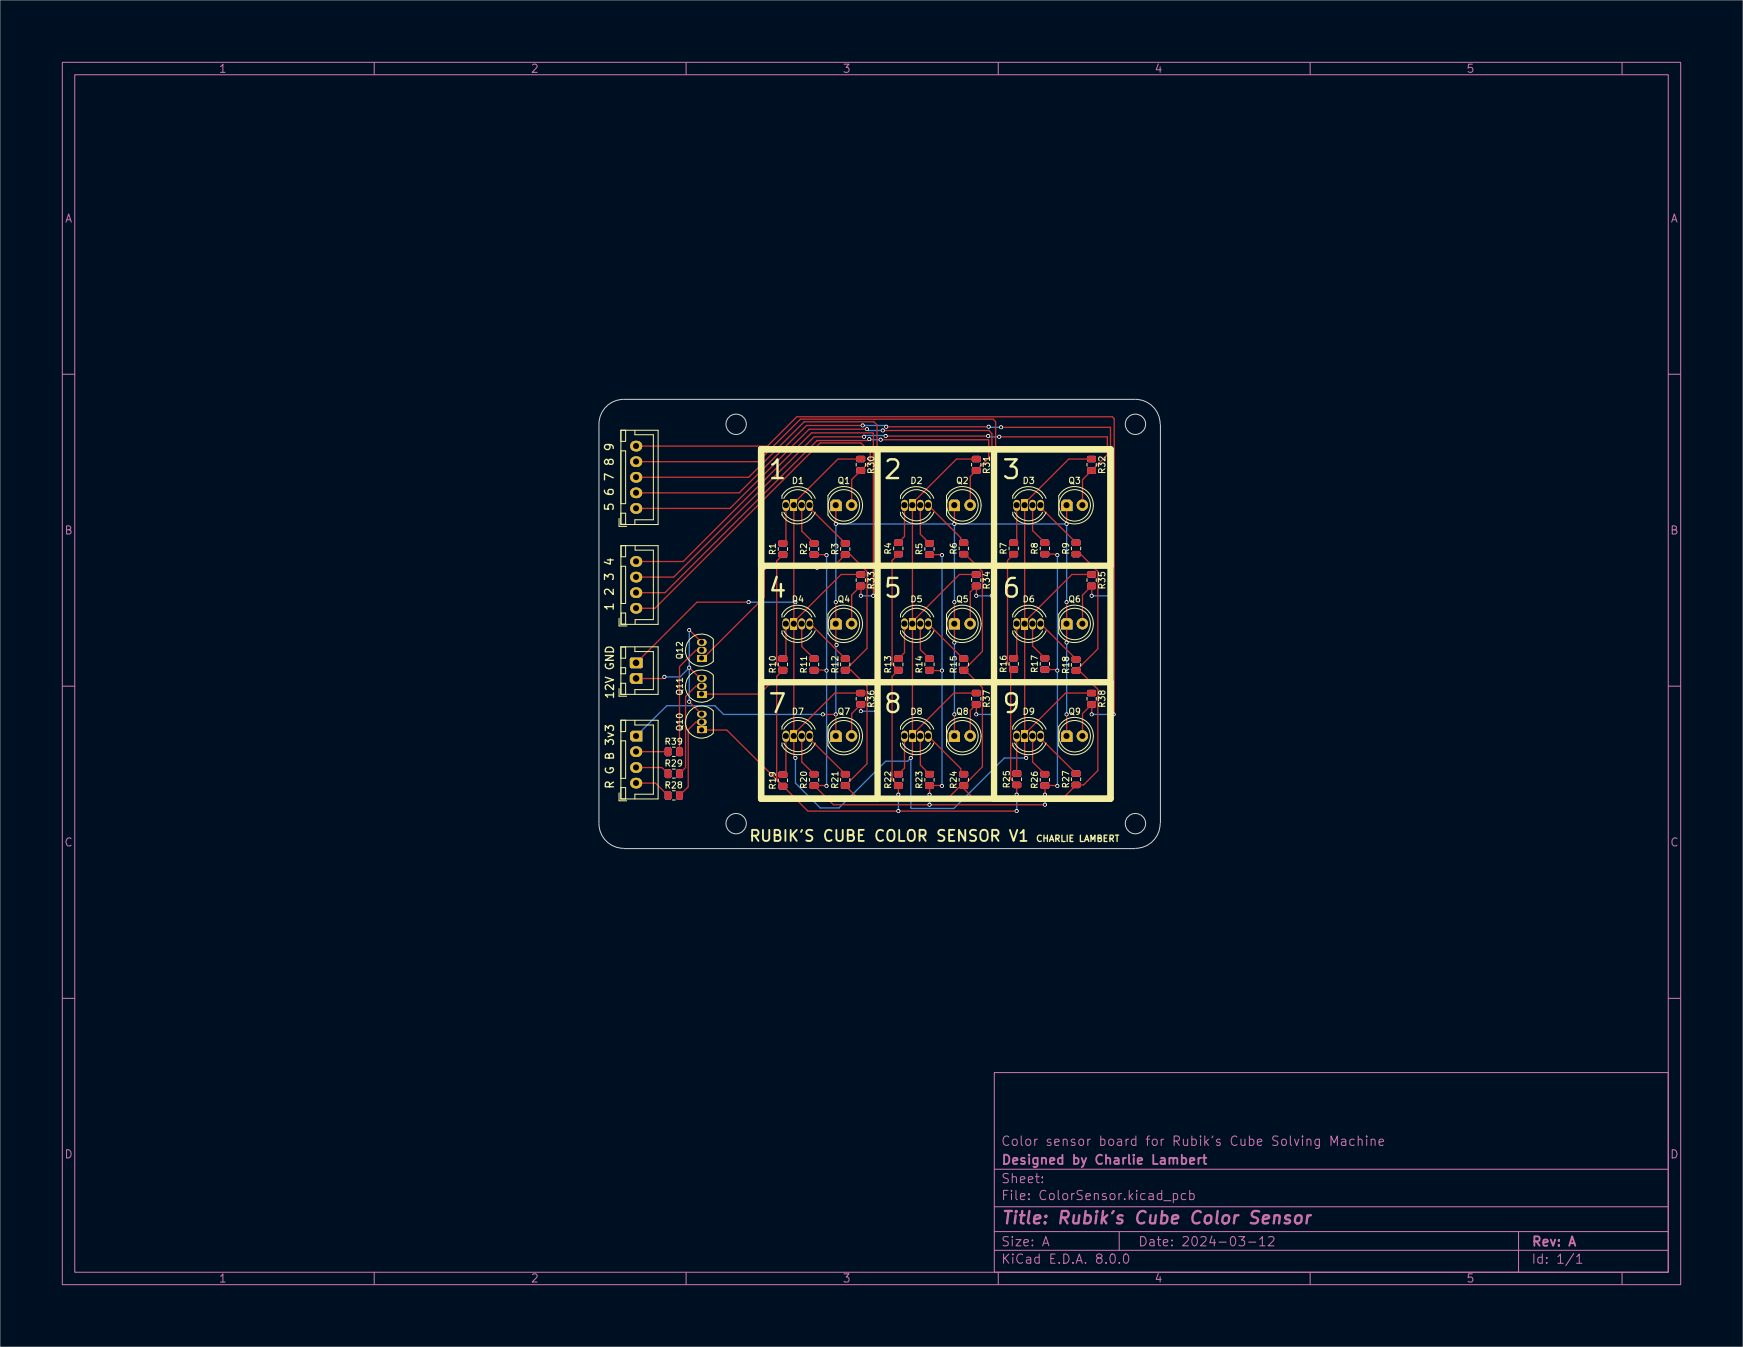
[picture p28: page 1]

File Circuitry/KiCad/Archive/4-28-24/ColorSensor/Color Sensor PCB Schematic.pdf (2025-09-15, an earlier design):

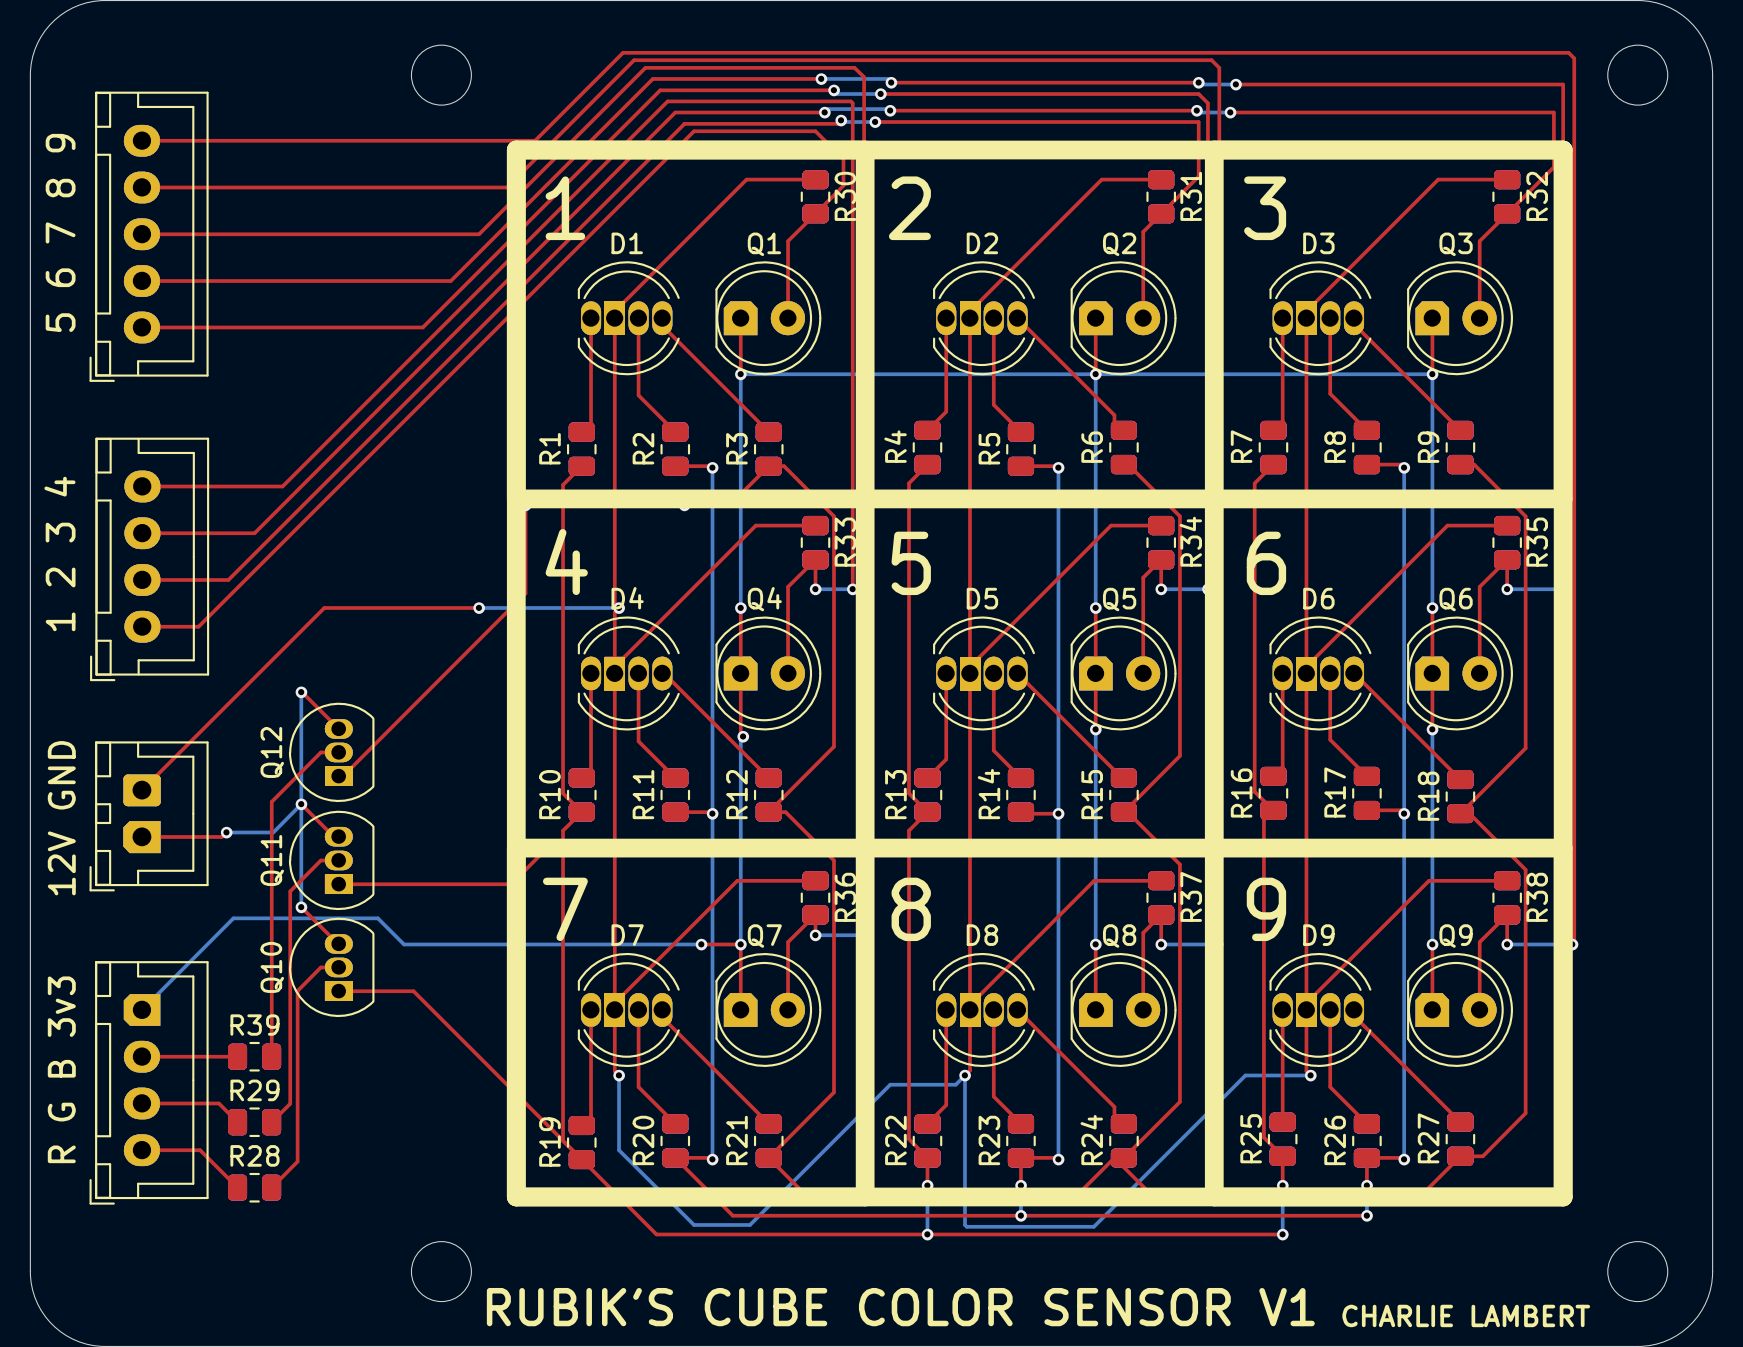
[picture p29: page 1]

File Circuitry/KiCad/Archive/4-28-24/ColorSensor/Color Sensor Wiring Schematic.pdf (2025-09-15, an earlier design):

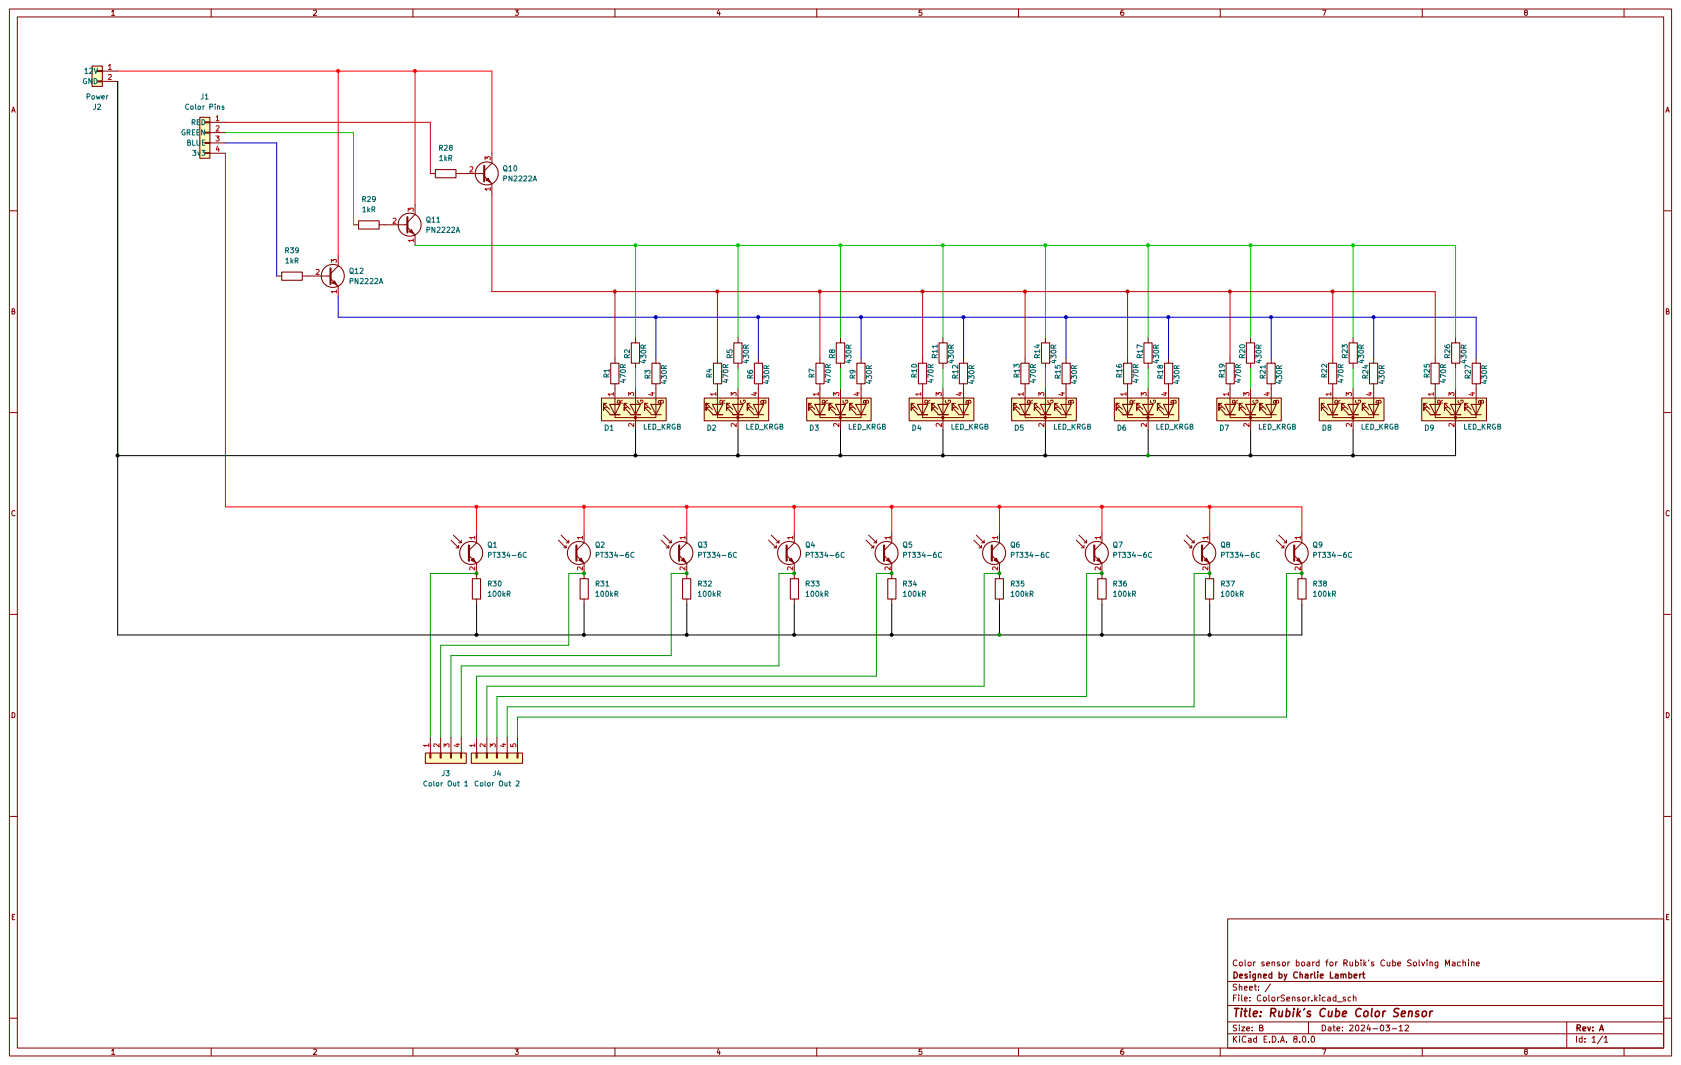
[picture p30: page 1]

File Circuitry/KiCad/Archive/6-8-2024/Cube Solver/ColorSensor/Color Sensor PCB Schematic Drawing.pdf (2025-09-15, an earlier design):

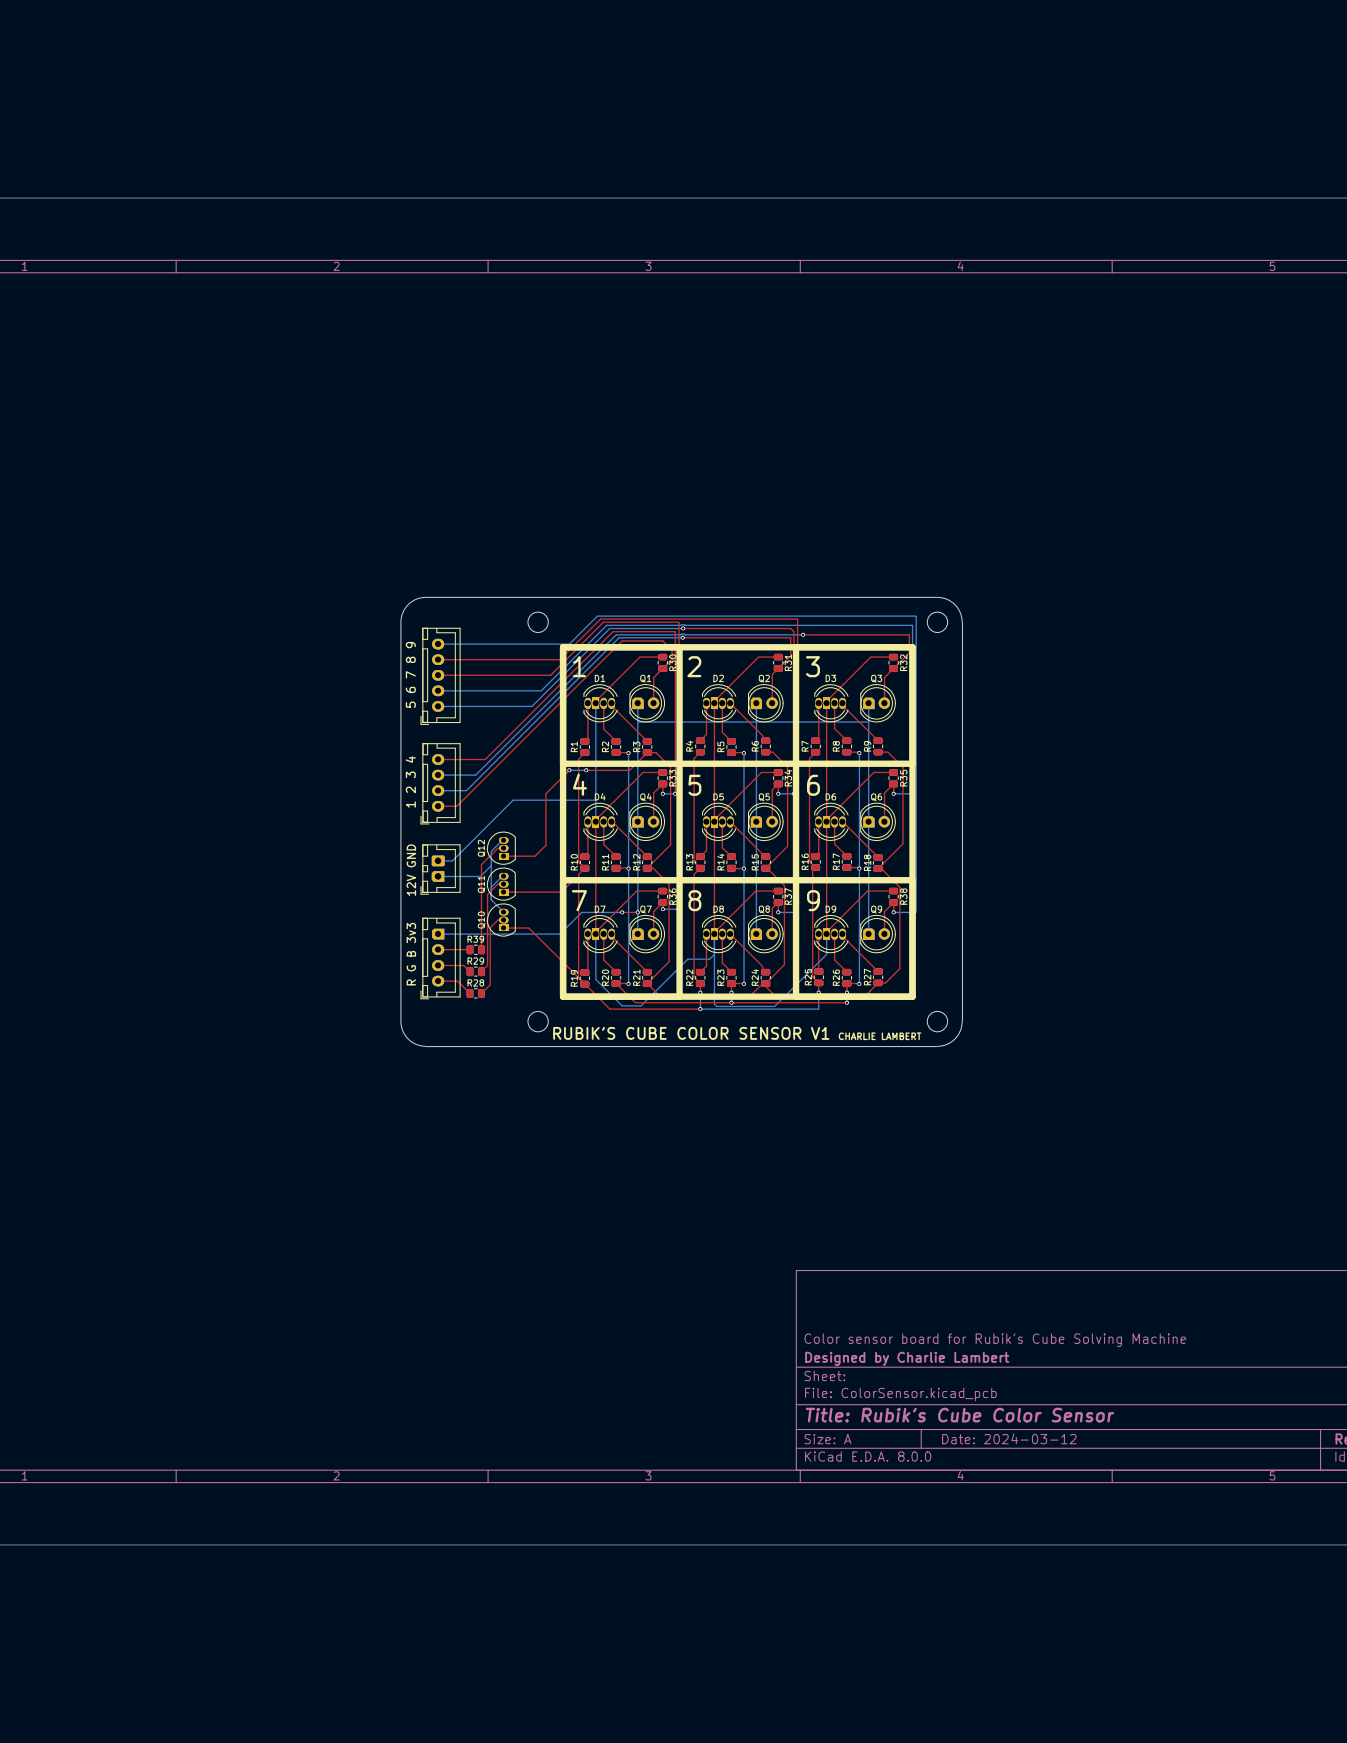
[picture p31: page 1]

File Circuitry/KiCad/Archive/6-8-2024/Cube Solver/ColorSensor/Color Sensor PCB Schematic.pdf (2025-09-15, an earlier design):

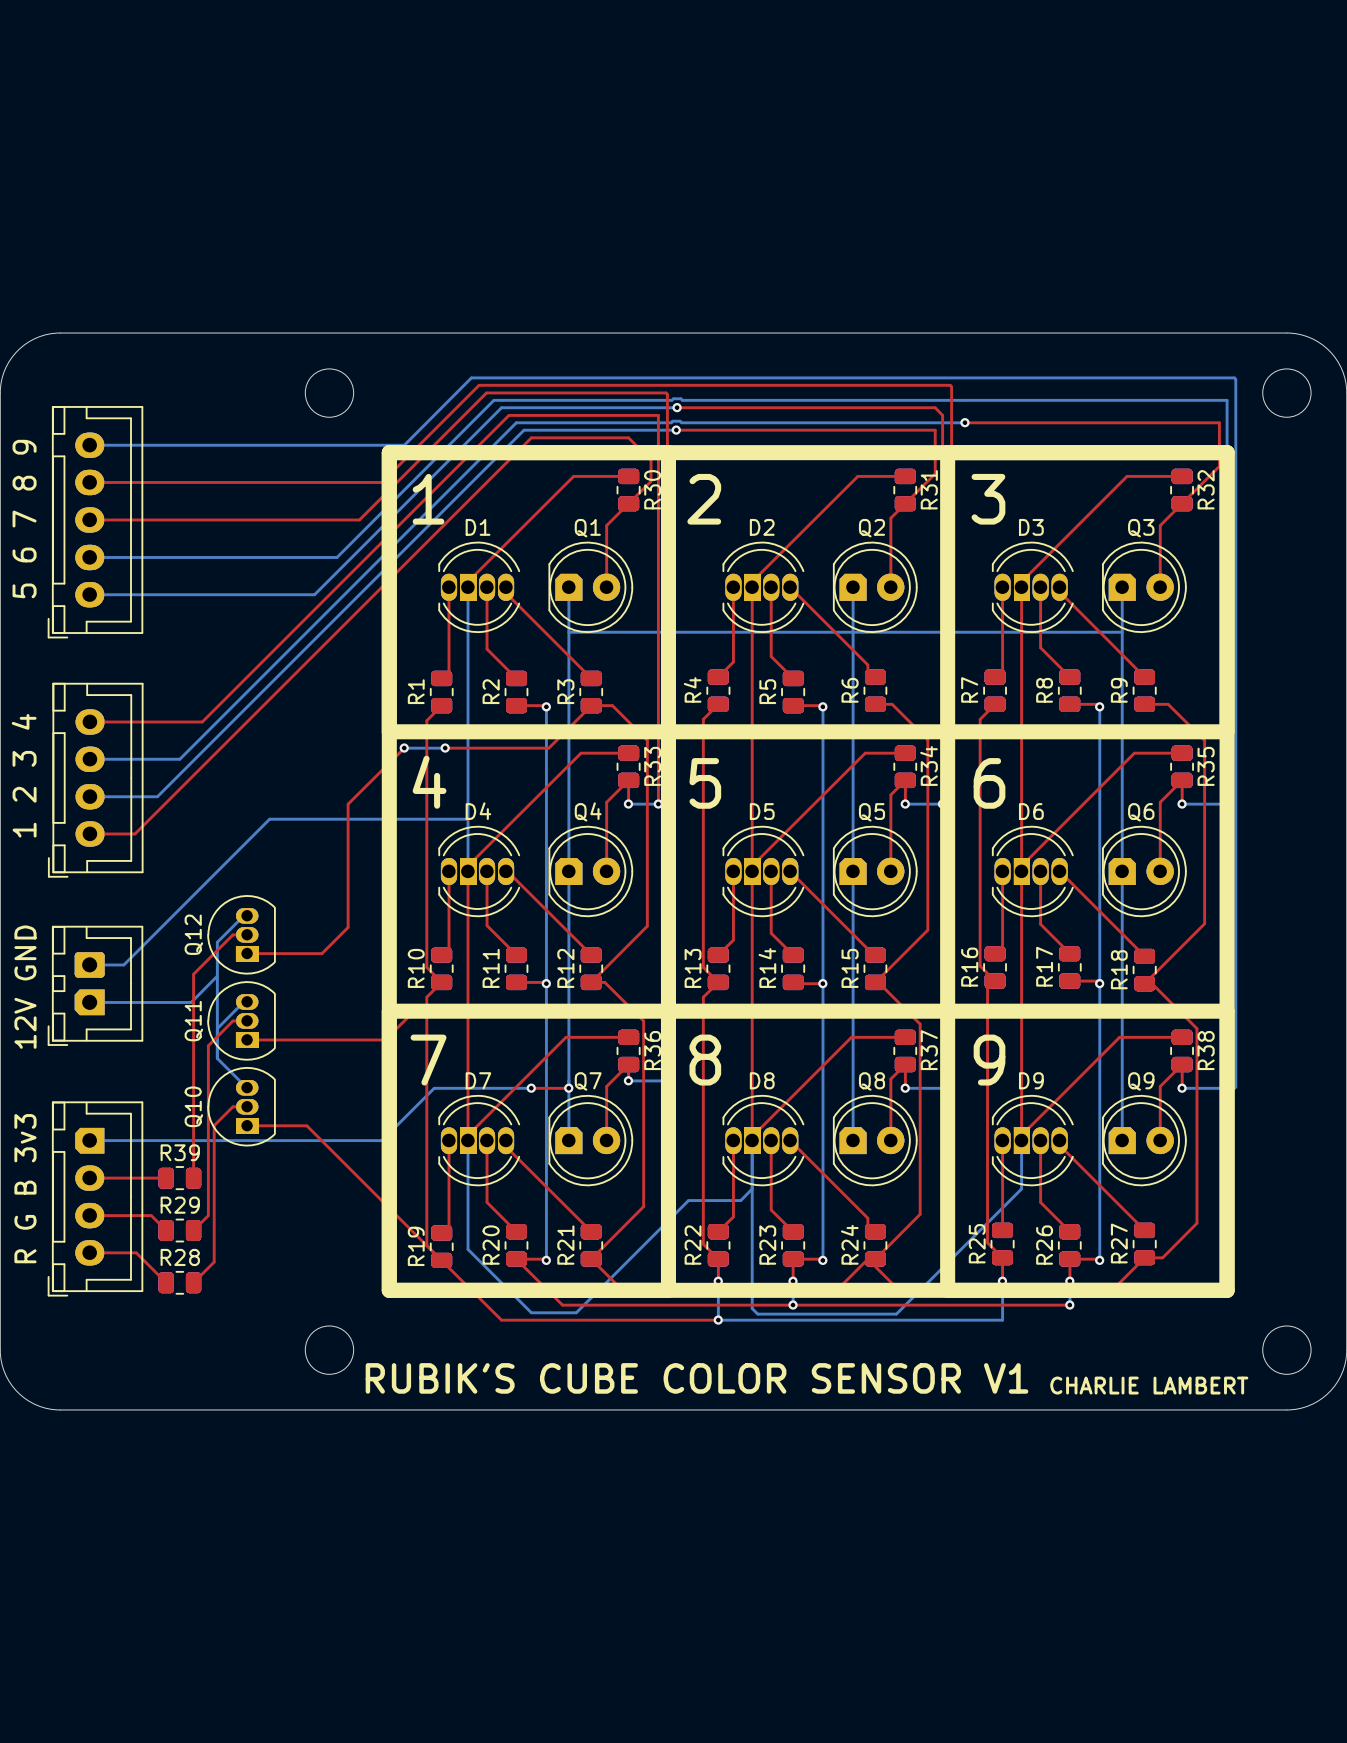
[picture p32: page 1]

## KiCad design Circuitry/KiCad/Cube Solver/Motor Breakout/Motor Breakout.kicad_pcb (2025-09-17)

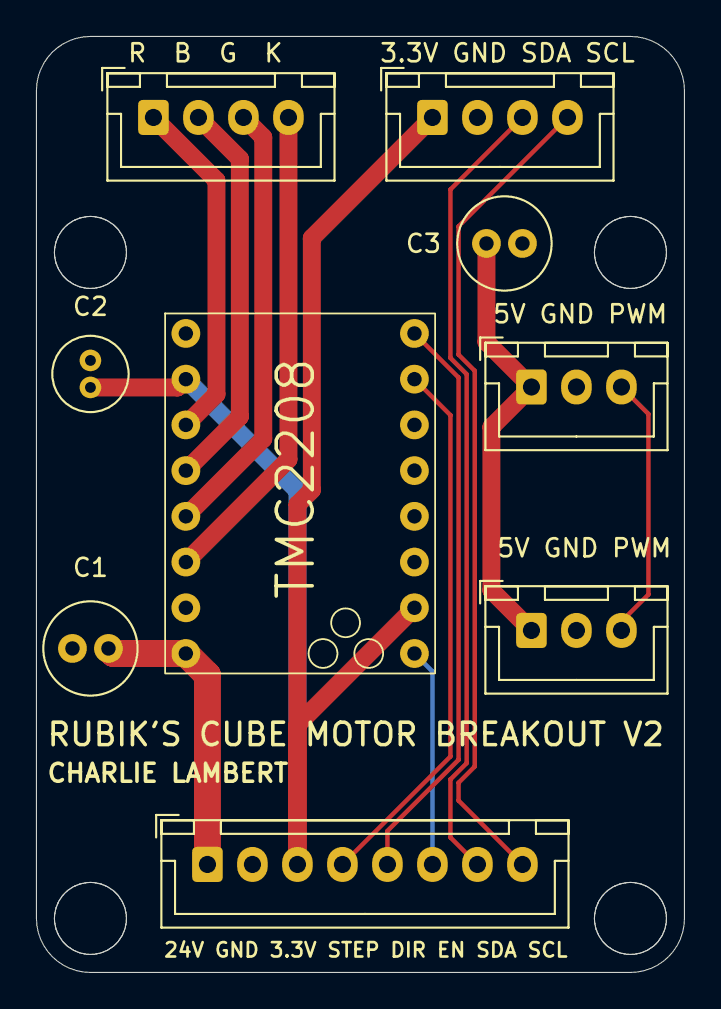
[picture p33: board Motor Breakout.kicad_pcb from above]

Board: 2 copper layers, 36.0 x 52.0 mm, 9 parts (0 on the bottom side), 14 nets.

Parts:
C1, C3: 100µF; C_Radial_D5.0mm_H11.0mm_P2.00mm
C2: 0.1µF; C_Radial_D4.0mm_H7.0mm_P1.50mm
J2: Motor Input; JST_XH_B4B-XH-A_1x04_P2.50mm_Vertical
J3: Motherboard Breakout; JST_XH_B8B-XH-A_1x08_P2.50mm_Vertical
J4: Servo Input; JST_XH_B3B-XH-A_1x03_P2.50mm_Vertical
J5: Servo Output; JST_XH_B3B-XH-A_1x03_P2.50mm_Vertical
J6: Encoder Input; JST_XH_B4B-XH-A_1x04_P2.50mm_Vertical
U1: TMC2208_Breakout

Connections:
+3.3V: C2.2, J3.3 (3.3V), J6.1 (VCC), U1.2 (VIO), U1.15 (MS1)
+5V: C3.1, J4.1 (5V), J5.1 (5V)
+24V: C1.1, J3.1 (24V), U1.8 (VMOT)
/Black: J2.4 (Black), U1.6 (M2B)
/Blue: J2.2 (Blue), U1.4 (M2A)
/Green: J2.3 (Green), U1.5 (M1A)
/Red: J2.1 (Red), U1.3 (M2B)
DIR: J3.5 (DIR), U1.9 (DIR)
EN: J3.6 (EN), U1.16 (EN)
GND: C1.2, C2.1, C3.2, J3.2 (GND), J4.2 (GND), J5.2 (GND), J6.2 (GND), U1.1 (GND), U1.7 (GND)
PWM: J4.3 (Signal), J5.3 (Signal)
SCL: J3.8 (SCL), J6.4 (SCL)
SDA: J3.7 (SDA), J6.3 (SDA)
STEP: J3.4 (STEP), U1.10 (STEP)

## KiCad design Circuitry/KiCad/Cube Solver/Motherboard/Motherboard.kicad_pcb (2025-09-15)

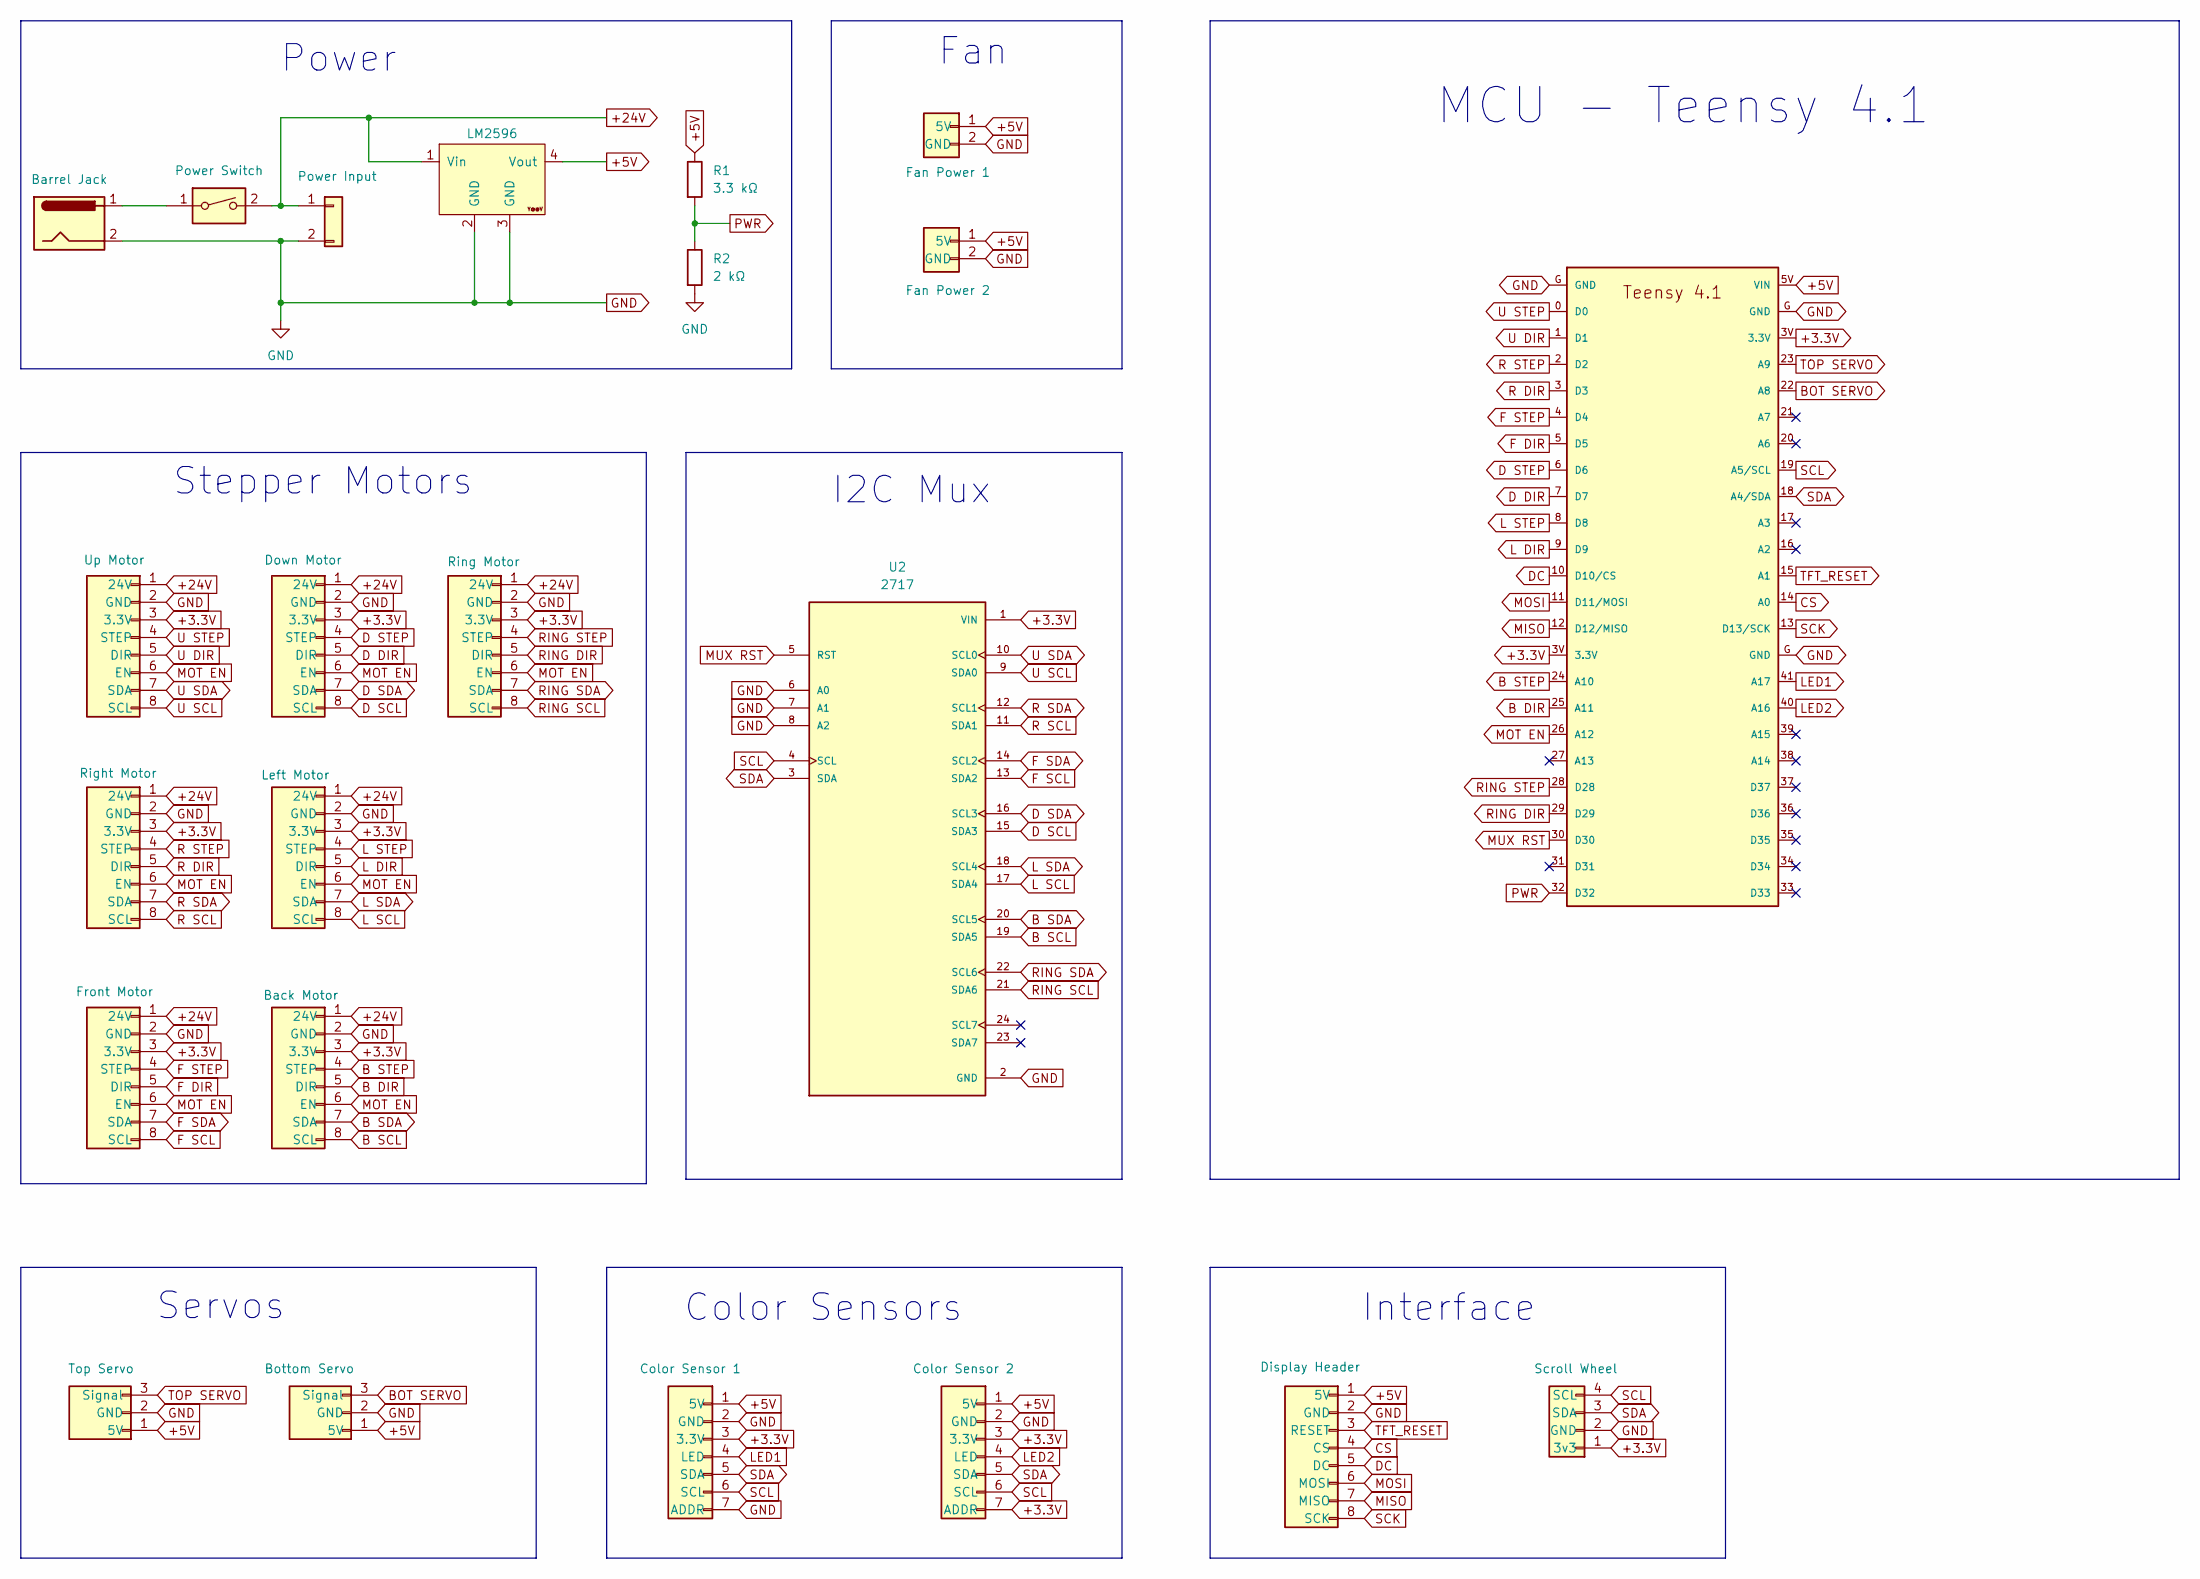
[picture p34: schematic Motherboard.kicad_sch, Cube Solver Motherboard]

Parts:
A1: TEENSY_4.1
J1: Color Sensor 1; JST_XH_B7B-XH-A_1x07_P2.50mm_Vertical
J2: Color Sensor 2; JST_XH_B7B-XH-A_1x07_P2.50mm_Vertical
J3: Top Servo; JST_XH_B3B-XH-A_1x03_P2.50mm_Vertical
J4: Bottom Servo; JST_XH_B3B-XH-A_1x03_P2.50mm_Vertical
J5: Up Motor; JST_XH_B8B-XH-A_1x08_P2.50mm_Vertical
J6: Down Motor; JST_XH_B8B-XH-A_1x08_P2.50mm_Vertical
J7: Ring Motor; JST_XH_B8B-XH-A_1x08_P2.50mm_Vertical
J8: Right Motor; JST_XH_B8B-XH-A_1x08_P2.50mm_Vertical
J9: Left Motor; JST_XH_B8B-XH-A_1x08_P2.50mm_Vertical
J10: Back Motor; JST_XH_B8B-XH-A_1x08_P2.50mm_Vertical
J11: Front Motor; JST_XH_B8B-XH-A_1x08_P2.50mm_Vertical
J12: Barrel Jack
J13: Display Header; JST_XH_B8B-XH-A_1x08_P2.50mm_Vertical
J14: Power Input; AMASS_XT60-M_1x02_P7.20mm_Vertical
J15: Fan Power 1; JST_XH_B2B-XH-AM_1x02_P2.50mm_Vertical
J16: Fan Power 2; JST_XH_B2B-XH-AM_1x02_P2.50mm_Vertical
J17: Scroll Wheel; JST_XH_B4B-XH-A_1x04_P2.50mm_Vertical
R1: 3.3 kΩ; R_Axial_DIN0207_L6.3mm_D2.5mm_P10.16mm_Horizontal
R2: 2 kΩ; R_Axial_DIN0207_L6.3mm_D2.5mm_P10.16mm_Horizontal
SW1: Power Switch
U1: LM2596; YAAJ_DCDC_StepDown_LM2596
U2: 2717; MODULE_2717; PARTREV Sep 11, 2015

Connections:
+3.3V: A1.3V (3.3V), J1.3 (3.3V), J2.3 (3.3V), J2.7 (ADDR), J5.3 (3.3V), J6.3 (3.3V), J7.3 (3.3V), J8.3 (3.3V), J9.3 (3.3V), J10.3 (3.3V), J11.3 (3.3V), J17.1 (3v3), U2.1 (VIN)
+5V: A1.5V (VIN), J1.1 (5V), J2.1 (5V), J3.1 (5V), J4.1 (5V), J13.1 (5V), J15.1 (5V), J16.1 (5V), R1.1, U1.4 (Vout)
+24V: J5.1 (24V), J6.1 (24V), J7.1 (24V), J8.1 (24V), J9.1 (24V), J10.1 (24V), J11.1 (24V), J14.1, SW1.2, U1.1 (Vin)
B DIR: A1.25 (A11), J10.5 (DIR)
B SCL: J10.8 (SCL), U2.19 (SDA5)
B SDA: J10.7 (SDA), U2.20 (SCL5)
B STEP: A1.24 (A10), J10.4 (STEP)
BOT SERVO: A1.22 (A8), J4.3 (Signal)
CS: A1.14 (A0), J13.4 (CS)
D DIR: A1.7 (D7), J6.5 (DIR)
D SCL: J6.8 (SCL), U2.15 (SDA3)
D SDA: J6.7 (SDA), U2.16 (SCL3)
D STEP: A1.6 (D6), J6.4 (STEP)
DC: A1.10 (D10/CS), J13.5 (DC)
F DIR: A1.5 (D5), J11.5 (DIR)
F SCL: J11.8 (SCL), U2.13 (SDA2)
F SDA: J11.7 (SDA), U2.14 (SCL2)
F STEP: A1.4 (D4), J11.4 (STEP)
GND: A1.G (GND), J1.2 (GND), J1.7 (ADDR), J2.2 (GND), J3.2 (GND), J4.2 (GND), J5.2 (GND), J6.2 (GND), J7.2 (GND), J8.2 (GND), J9.2 (GND), J10.2 (GND), J11.2 (GND), J12.2, J13.2 (GND), J14.2, J15.2 (GND), J16.2 (GND), J17.2 (GND), R2.2, U1.2 (GND), U1.3 (GND), U2.2 (GND), U2.6 (A0), U2.7 (A1), U2.8 (A2)
L DIR: A1.9 (D9), J9.5 (DIR)
L SCL: J9.8 (SCL), U2.17 (SDA4)
L SDA: J9.7 (SDA), U2.18 (SCL4)
L STEP: A1.8 (D8), J9.4 (STEP)
LED1: A1.41 (A17), J1.4 (LED)
LED2: A1.40 (A16), J2.4 (LED)
MISO: A1.12 (D12/MISO), J13.7 (MISO)
MOSI: A1.11 (D11/MOSI), J13.6 (MOSI)
MOT EN: A1.26 (A12), J5.6 (EN), J6.6 (EN), J7.6 (EN), J8.6 (EN), J9.6 (EN), J10.6 (EN), J11.6 (EN)
MUX RST: A1.30 (D30), U2.5 (RST)
unnamed: J12.1, SW1.1
PWR: A1.32 (D32), R1.2, R2.1
R DIR: A1.3 (D3), J8.5 (DIR)
R SCL: J8.8 (SCL), U2.11 (SDA1)
R SDA: J8.7 (SDA), U2.12 (SCL1)
R STEP: A1.2 (D2), J8.4 (STEP)
RING DIR: A1.29 (D29), J7.5 (DIR)
RING SCL: J7.8 (SCL), U2.21 (SDA6)
RING SDA: J7.7 (SDA), U2.22 (SCL6)
RING STEP: A1.28 (D28), J7.4 (STEP)
SCK: A1.13 (D13/SCK), J13.8 (SCK)
SCL: A1.19 (A5/SCL), J1.6 (SCL), J2.6 (SCL), J17.4 (SCL), U2.4 (SCL)
SDA: A1.18 (A4/SDA), J1.5 (SDA), J2.5 (SDA), J17.3 (SDA), U2.3 (SDA)
TFT_RESET: A1.15 (A1), J13.3 (RESET)
TOP SERVO: A1.23 (A9), J3.3 (Signal)
U DIR: A1.1 (D1), J5.5 (DIR)
U SCL: J5.8 (SCL), U2.9 (SDA0)
U SDA: J5.7 (SDA), U2.10 (SCL0)
U STEP: A1.0 (D0), J5.4 (STEP)

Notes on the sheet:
Fan
I2C Mux
Power
Color Sensors
Interface
Servos
Stepper Motors
MCU - Teensy 4.1

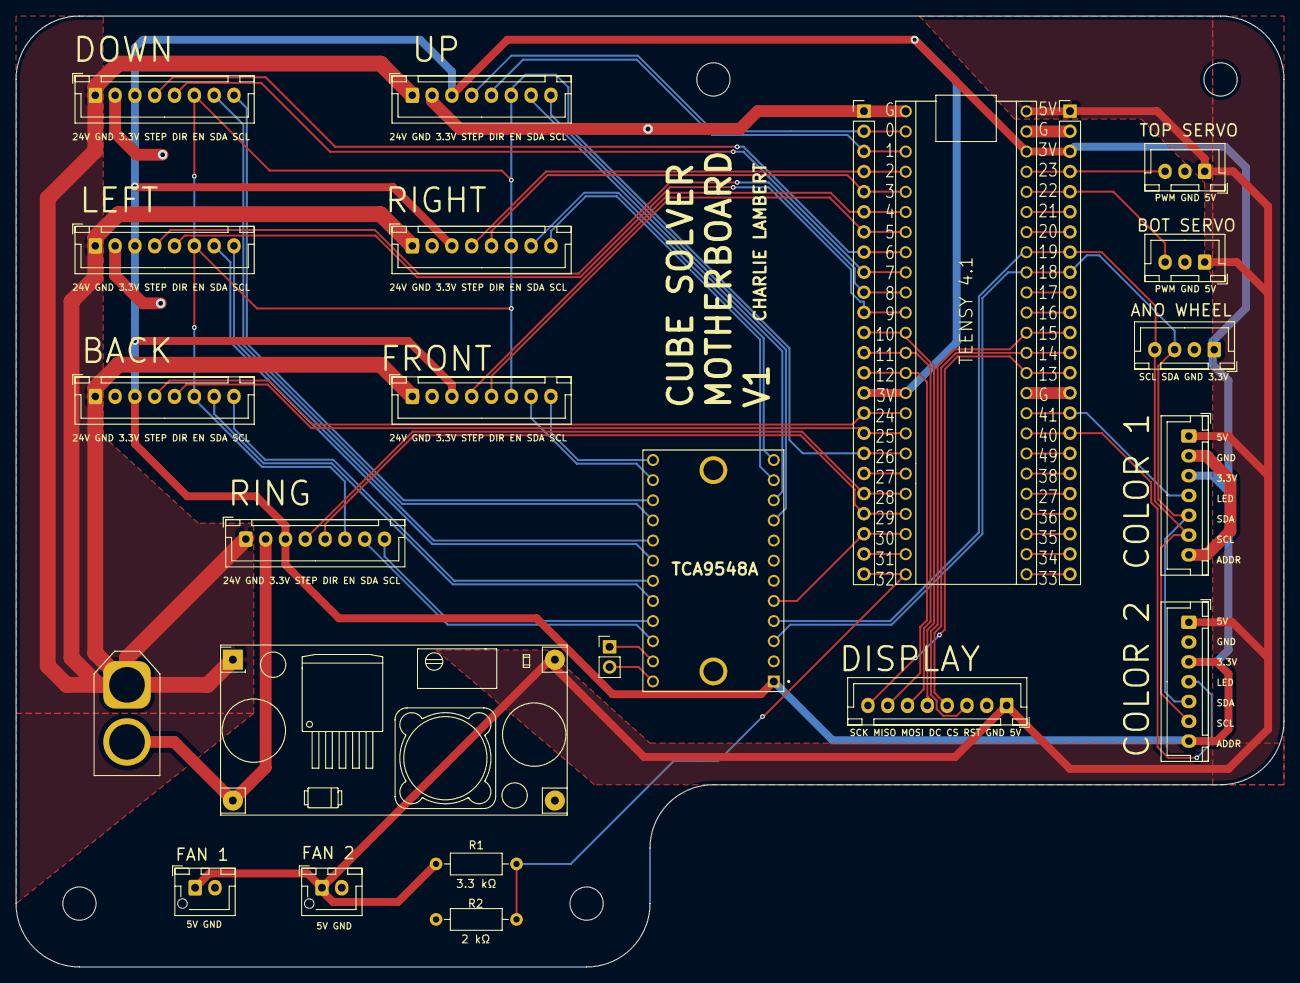
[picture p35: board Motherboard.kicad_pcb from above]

Board: 2 copper layers, 160.0 x 120.0 mm, 21 parts (0 on the bottom side), 47 nets.

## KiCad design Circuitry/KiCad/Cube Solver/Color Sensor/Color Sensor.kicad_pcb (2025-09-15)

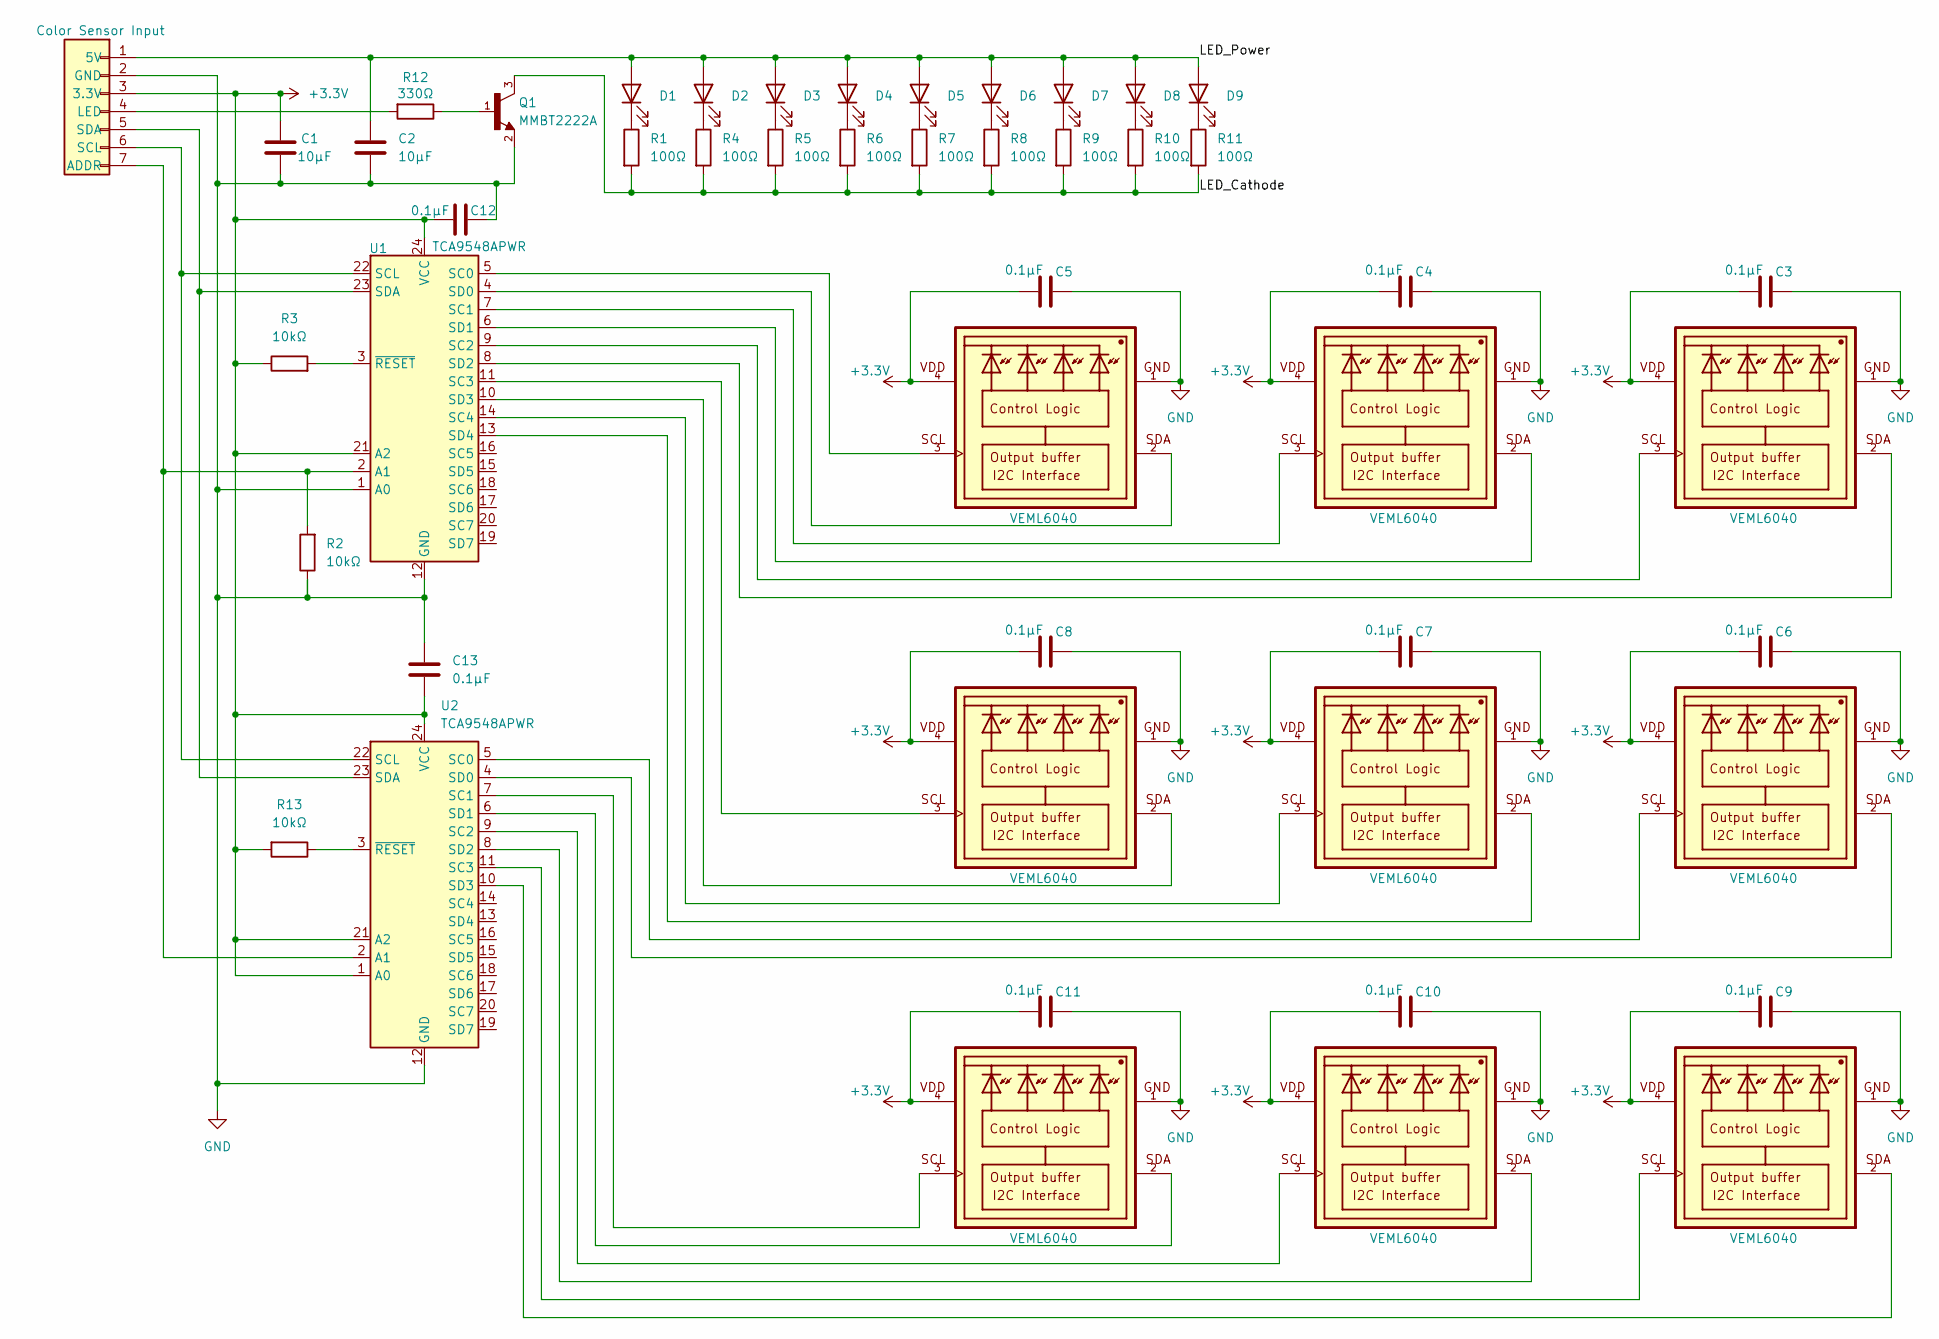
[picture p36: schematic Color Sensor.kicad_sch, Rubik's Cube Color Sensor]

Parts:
C1, C2: 10µF; C_0805_2012Metric
C3, C4, C5, C6, C7, C8, C9, C10, C11, C12, C13: 0.1µF; C_0805_2012Metric
D1, D2, D3, D4, D5, D6, D7, D8, D9: GW JTLMS3.GM-G6GV-XX55-1-60-R33; LED_PLCC_2835
J1: Color Sensor Input; JST_XH_S7B-XH-A-1_1x07_P2.50mm_Horizontal
Q1: MMBT2222A; SOT23
R1, R4, R5, R6, R7, R8, R9, R10, R11: 100Ω; R_0805_2012Metric
R2, R3, R13: 10kΩ; R_0805_2012Metric
R12: 330Ω; R_0805_2012Metric
U1, U2: TCA9548APWR; TSSOP-24_4.4x7.8mm_P0.65mm
U3, U4, U5, U6, U7, U8, U9, U10, U11: VEML6040; VISHAY_VEML6040_1.25X2X1

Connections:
+3.3V: C1.1, C3.2, C4.2, C5.2, C6.2, C7.2, C8.2, C9.2, C10.2, C11.2, C12.2, C13.2, J1.3 (3.3V), R3.1, R13.2, U1.21 (A2), U1.24 (VCC), U2.1 (A0), U2.21 (A2), U2.24 (VCC), U3.4, U4.4, U5.4, U6.4, U7.4, U8.4, U9.4, U10.4, U11.4
/LED_Cathode: Q1.3, R1.2, R4.2, R5.2, R6.2, R7.2, R8.2, R9.2, R10.2, R11.2
/LED_Power: C2.1, D1.2 (A), D2.2 (A), D3.2 (A), D4.2 (A), D5.2 (A), D6.2 (A), D7.2 (A), D8.2 (A), D9.2 (A), J1.1 (5V)
GND: C1.2, C2.2, C3.1, C4.1, C5.1, C6.1, C7.1, C8.1, C9.1, C10.1, C11.1, C12.1, C13.1, J1.2 (GND), Q1.2, R2.1, U1.1 (A0), U1.12 (GND), U2.12 (GND), U3.1, U4.1, U5.1, U6.1, U7.1, U8.1, U9.1, U10.1, U11.1
unnamed: D1.1 (K), R1.1
unnamed: D2.1 (K), R4.1
unnamed: D3.1 (K), R5.1
unnamed: D4.1 (K), R6.1
unnamed: D5.1 (K), R7.1
unnamed: D6.1 (K), R8.1
unnamed: D7.1 (K), R9.1
unnamed: D8.1 (K), R10.1
unnamed: D9.1 (K), R11.1
unnamed: J1.7 (ADDR), R2.2, U1.2 (A1), U2.2 (A1)
unnamed: J1.4 (LED), R12.2
unnamed: J1.6 (SCL), U1.22 (SCL), U2.22 (SCL)
unnamed: J1.5 (SDA), U1.23 (SDA), U2.23 (SDA)
unnamed: Q1.1, R12.1
unnamed: U1.5 (SC0), U5.3
unnamed: U1.7 (SC1), U4.3
unnamed: U1.9 (SC2), U3.3
unnamed: U1.11 (SC3), U8.3
unnamed: U1.14 (SC4), U7.3
unnamed: U1.4 (SD0), U5.2
unnamed: U1.6 (SD1), U4.2
unnamed: U1.8 (SD2), U3.2
unnamed: U1.10 (SD3), U8.2
unnamed: U1.13 (SD4), U7.2
unnamed: R3.2, U1.3 (~RESET)
unnamed: U2.5 (SC0), U6.3
unnamed: U2.7 (SC1), U11.3
unnamed: U2.9 (SC2), U10.3
unnamed: U2.11 (SC3), U9.3
unnamed: U2.4 (SD0), U6.2
unnamed: U2.6 (SD1), U11.2
unnamed: U2.8 (SD2), U10.2
unnamed: U2.10 (SD3), U9.2
unnamed: R13.1, U2.3 (~RESET)

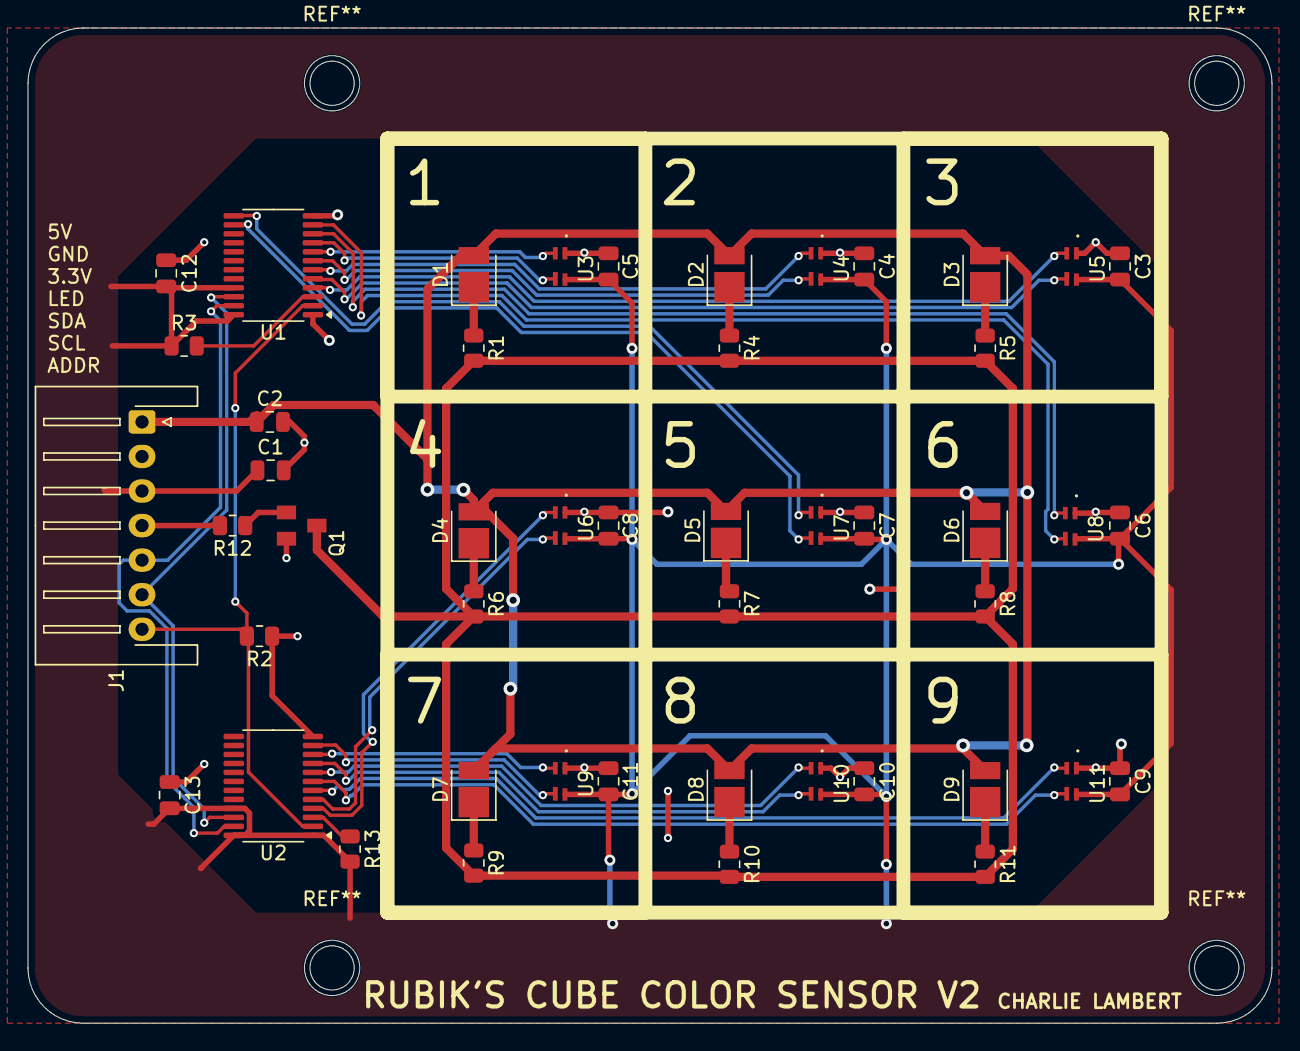
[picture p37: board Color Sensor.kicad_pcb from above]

Board: 2 copper layers, 90.0 x 72.0 mm, 48 parts (0 on the bottom side), 38 nets.

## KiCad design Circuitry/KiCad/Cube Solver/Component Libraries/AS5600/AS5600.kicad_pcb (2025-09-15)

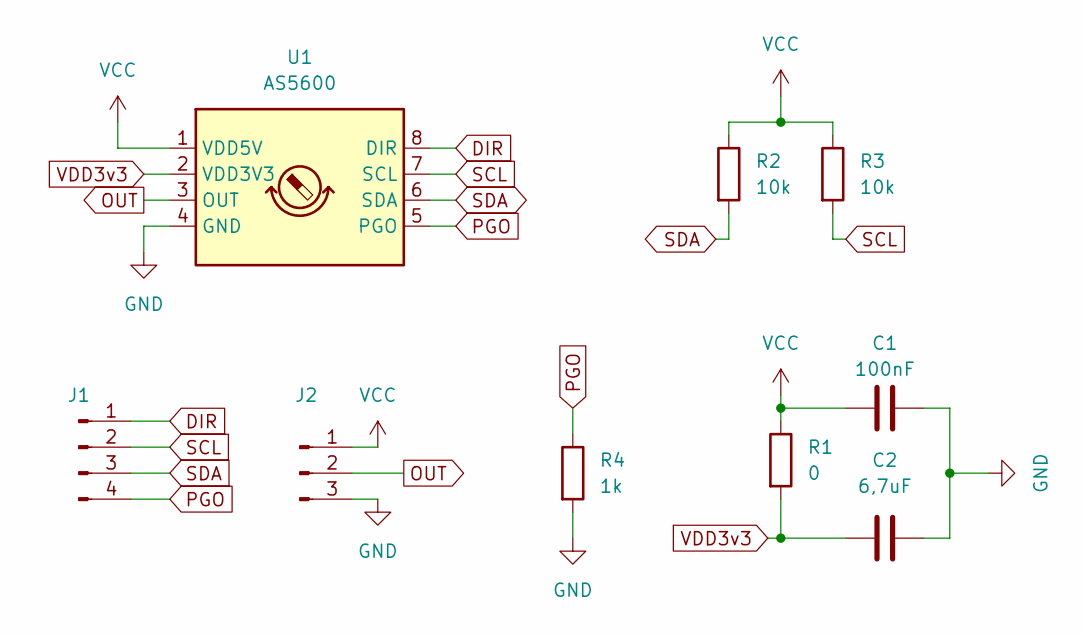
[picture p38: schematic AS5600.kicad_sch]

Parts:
C1: 100nF; C_0805_2012Metric_Pad1.18x1.45mm_HandSolder
C2: 6,7uF; C_0805_2012Metric_Pad1.18x1.45mm_HandSolder
J1: Conn_01x04_Male; PinHeader_1x04_P2.54mm_Vertical
J2: Conn_01x03_Male; PinHeader_1x03_P2.54mm_Vertical
R1: 0; R_0805_2012Metric_Pad1.20x1.40mm_HandSolder
R2, R3: 10k; R_0805_2012Metric_Pad1.20x1.40mm_HandSolder
R4: 1k; R_0805_2012Metric_Pad1.20x1.40mm_HandSolder
U1: AS5600; SOIC-8_3.9x4.9mm_P1.27mm

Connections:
DIR: J1.1, U1.8 (DIR)
GND: C1.2, C2.2, J2.3, R4.2, U1.4 (GND)
OUT: J2.2, U1.3 (OUT)
PGO: J1.4, R4.1, U1.5 (PGO)
SCL: J1.2, R3.2, U1.7 (SCL)
SDA: J1.3, R2.2, U1.6 (SDA)
VCC: C1.1, J2.1, R1.1, R2.1, R3.1, U1.1 (VDD5V)
VDD3v3: C2.1, R1.2, U1.2 (VDD3V3)

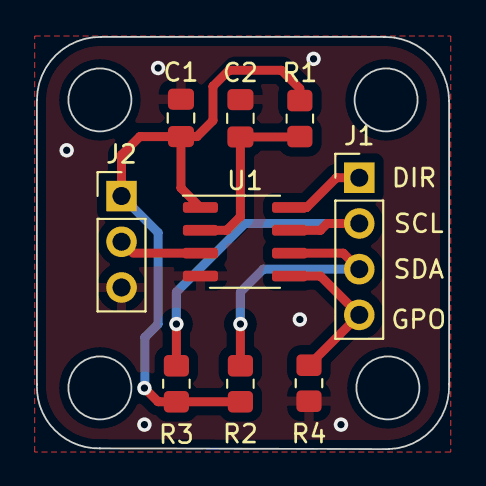
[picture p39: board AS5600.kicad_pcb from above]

Board: 2 copper layers, 22.9 x 22.9 mm, 9 parts (0 on the bottom side), 8 nets.

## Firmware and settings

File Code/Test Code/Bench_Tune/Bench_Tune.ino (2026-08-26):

// Bench_Tune — drive the machine over Serial and get every encoder reading
// back, so motion parameters can be tuned from a script instead of by hand.
//
// WHAT IT IS FOR
// --------------
// The firmware's moves are open loop with an encoder check afterwards, and
// the only evidence of a bad move today is a jam. This sketch runs the SAME
// library code (CubeMotors, CubeSystem::checkAlignment/homeMotors) but
// reports, for every move, where each motor's encoder stood before, where it
// stood after, how far that is from where the commanded steps should have put
// it, and which calibration mark it is nearest. Run a few hundred moves at a
// setting and the residual distribution says whether that setting loses
// steps. Change one parameter and run again.
//
// It is headless — begin(kNoDisplay) — so the panel never competes with a
// step loop for time. The abort chord still works (the pump is registered),
// and any byte arriving on Serial during a repeat run stops it at the next
// move boundary.
//
// PROTOCOL (line oriented, ASCII, for a script to parse)
// ------------------------------------------------------
// Every command is answered by zero or more TAGGED data lines and then exactly
// one terminator: `ok` or `err <n> <text>`. Lines starting with `#` are for a
// human; lines starting with `[` are the library's own diagnostics
// ([align] ...). Motor order everywhere is U R F D L B (RING seventh).
//
//   help                      this list
//   status                    status hold= en= ring= top= bot= calibrated= boothome= align=
//   get                       param speed= accel= delay= rotdelay= dwell= tol= hometimeout= turnstep= hold= align=
//   set <name> <value>        names as in `get`; ranges are the library's own clamps
//   enc                       enc U=<raw> ... RING=<raw>   (negative = I2C error)
//                             near U=<idx>:<err> ...      (nearest mark, signed error)
//   cal                       cal <M> <m0> <m1> <m2> <m3> gaps <g01> <g12> <g23> <g30>
//   noise <motor> <n>         noise <M> n= min= max= mean=   (n back-to-back reads)
//   relax                     relax U=<energised>/<relaxed>/<delta> ...  (needs hold off)
//   hold on|off               keep all face motors energised between moves
//   align on|off              run checkAlignment()+homeMotors() after each move (default on)
//   load | unload             the real clamp / release sequences
//   servo top|bot ext|ret|partial|eject
//   ring ext|ret|mid|partial
//   home                      home code=<c> ms=<t>  then enc/near lines
//   move <tok>                one move; prints a mv record (below)
//   seq <tok> <tok> ...       each move in turn; stops at the first failure
//   rep <n> <tok> ...         the sequence n times; stops on failure or any Serial byte;
//                             prints a rep summary
//   stop                      holdEnd() + disableMotors()
//
// The move record:
//   mv <tok> code=<c> aligned=<0|1> homed=<-|code> ms=<move_ms>
//      U=<before>,<after>,<res>,<idx>,<err> R=... F=... D=... L=... B=...
//   before/after  raw encoder counts around the physical move
//   res           after minus where the commanded steps should have put it,
//                 shortest way round, in counts (10.24 per step). A residual
//                 near +-2048 on a quarter turn means the sign convention
//                 (CubeSystem::kAlignStepSign) is wrong, not the motor.
//   idx, err      nearest calibration mark after the move and the signed
//                 error to it
//   ms            the physical move including its settle; the alignment
//                 check and any homing are NOT in it
//
// Move tokens are exactly CubeMotors::executeMove()'s: U U' U2 ... B2, plus
// ROTX ROTZ ALL.

#include <CubeSystem.h>
#include <CubePump.h>

CubeSystem Cube;                    // CubeTuneTable.cpp links against this name

static const int  kMotors = 6;
static const char* const kNames[7] = {"U", "R", "F", "D", "L", "B", "RING"};

static bool alignMode = true;
static char lineBuf[160];
static int  lineLen = 0;

// ---------------------------------------------------------------- helpers --

static void ok()                          { Serial.println(F("ok")); }
static void err(int n, const char* text)  { Serial.print(F("err ")); Serial.print(n); Serial.print(' '); Serial.println(text); }

static bool validToken(const char* t) {
    for (int f = 0; f < 6; ++f)
        for (int k = 0; k < 3; ++k)
            if (strcmp(t, CubeSystem::kFaceMoves[f][k]) == 0) return true;
    return strcmp(t, "ROTX") == 0 || strcmp(t, "ROTZ") == 0 || strcmp(t, "ALL") == 0;
}

static void readAll(int out[7]) {
    for (int i = 0; i < 7; ++i) out[i] = MotorEncoders[i]->scanChecked();
}

// Nearest calibration mark and signed error to it, the aligner's own test.
static int nearestMark(int motor, int raw, int* errOut) {
    int best = 0, bestErr = 4096;
    for (int j = 0; j < 4; ++j) {
        int e = CubeSystem::encError(raw, MotorEncoders[motor]->getCalibration(j));
        if (abs(e) < abs(bestErr)) { bestErr = e; best = j; }
    }
    if (errOut) *errOut = bestErr;
    return best;
}

static void printEnc(const int v[7]) {
    Serial.print(F("enc"));
    for (int i = 0; i < 7; ++i) { Serial.print(' '); Serial.print(kNames[i]); Serial.print('='); Serial.print(v[i]); }
    Serial.println();
    if (!Cube.getMotorCalibration()) return;
    Serial.print(F("near"));
    for (int i = 0; i < kMotors; ++i) {
        Serial.print(' '); Serial.print(kNames[i]); Serial.print('=');
        if (v[i] < 0) { Serial.print(F("?:?")); continue; }
        int e; int k = nearestMark(i, v[i], &e);
        Serial.print(k); Serial.print(':'); Serial.print(e);
    }
    Serial.println();
}

static void cmdEnc() {
    int v[7]; readAll(v); printEnc(v); ok();
}

static void cmdStatus() {
    Serial.print(F("status hold=")); Serial.print(cubeMotors.isHeld() ? 1 : 0);
    Serial.print(F(" ring="));       Serial.print(cubeMotors.getRingState());
    Serial.print(F(" top="));        Serial.print(topServo.coarseState());
    Serial.print(F(" bot="));        Serial.print(botServo.coarseState());
    Serial.print(F(" calibrated=")); Serial.print(Cube.getMotorCalibration() ? 1 : 0);
    Serial.print(F(" boothome="));   Serial.print(Cube.motorHomeState);
    Serial.print(F(" align="));      Serial.print(alignMode ? 1 : 0);
    Serial.print(F(" encmux="));     Serial.print(Cube.encoderMuxOk ? 1 : 0);
    Serial.print(F(" encoders="));
    for (int i = 0; i < 7; ++i) Serial.print(Cube.motorEncoderOk[i] ? '1' : '0');
    Serial.println();
    ok();
}

static void cmdGet() {
    Serial.print(F("param speed="));  Serial.print(cubeMotors.getStepSpeed());
    Serial.print(F(" accel="));       Serial.print(cubeMotors.getStepAccel());
    Serial.print(F(" delay="));       Serial.print(cubeMotors.getStepDelay());
    Serial.print(F(" rotdelay="));    Serial.print(cubeMotors.getRotStepDelay());
    Serial.print(F(" dwell="));       Serial.print(cubeMotors.getEnableDwell());
    Serial.print(F(" tol="));         Serial.print(Cube.motorAlignmentTol);
    Serial.print(F(" hometimeout=")); Serial.print(Cube.homeTimeout);
    Serial.print(F(" turnstep="));    Serial.print(cubeMotors.getTurnStep());
    Serial.print(F(" hold="));        Serial.print(cubeMotors.isHeld() ? 1 : 0);
    Serial.print(F(" align="));       Serial.print(alignMode ? 1 : 0);
    Serial.println();
    ok();
}

static void cmdSet(const char* name, const char* value) {
    if (!name || !value) { err(2, "set <name> <value>"); return; }
    long v = atol(value);
    if      (!strcmp(name, "speed"))       cubeMotors.setStepSpeed((int)v);
    else if (!strcmp(name, "accel"))       cubeMotors.setStepAccel((int)v);
    else if (!strcmp(name, "delay"))       cubeMotors.setStepDelay((int)v);
    else if (!strcmp(name, "rotdelay"))    cubeMotors.setRotStepDelay((int)v);
    else if (!strcmp(name, "dwell"))       cubeMotors.setEnableDwell((int)v);
    // Tolerance floor 3, matching the tuning table (it was 8, lowered at the
    // owner's request for bench diagnosis). Knowingly below the safe line:
    // half a step is 5.12 counts, so under ~6 the step lattice may hold no
    // point inside the band and the aligner hunts to its timeout — expect
    // align-timeout faults at the bottom of the range. Ceiling 60 (~5 deg).
    else if (!strcmp(name, "tol"))         Cube.motorAlignmentTol = (int)constrain(v, 3, 60);
    else if (!strcmp(name, "hometimeout")) Cube.homeTimeout = (unsigned long)constrain(v, 200, 10000);
    else if (!strcmp(name, "hold"))        { if (v) cubeMotors.holdBegin(); else cubeMotors.holdEnd(); }
    else if (!strcmp(name, "align"))       alignMode = (v != 0);
    else { err(3, "unknown parameter"); return; }
    cmdGet();
}

static void cmdCal() {
    if (!Cube.getMotorCalibration()) { err(4, "motors not calibrated"); return; }
    for (int i = 0; i < kMotors; ++i) {
        int m[4];
        for (int j = 0; j < 4; ++j) m[j] = MotorEncoders[i]->getCalibration(j);
        Serial.print(F("cal ")); Serial.print(kNames[i]);
        for (int j = 0; j < 4; ++j) { Serial.print(' '); Serial.print(m[j]); }
        Serial.print(F(" gaps"));
        // Four gaps including the wrap: a sweep that lost steps puts the
        // short gap anywhere, and the wrap gap a quarter of the time.
        for (int j = 0; j < 4; ++j) { Serial.print(' '); Serial.print((m[(j + 1) % 4] - m[j]) & 0x0FFF); }
        Serial.println();
    }
    ok();
}

// The magnet as the AS5600 sees it, for all seven. `health` tells a moving
// magnet from a moving rotor: ANGLE cannot, MAGNITUDE and AGC can.
//   health U=md,ml,mh/agc/mag ...   flags are 1/0; mag is 12-bit field strength
static void cmdHealth() {
    Serial.print(F("health"));
    for (int i = 0; i < 7; ++i) {
        uint8_t st = 0, agc = 0; uint16_t mag = 0;
        int rc = MotorEncoders[i]->readHealth(&st, &agc, &mag);
        Serial.print(' '); Serial.print(kNames[i]); Serial.print('=');
        if (rc != 0) { Serial.print(F("err")); Serial.print(rc); continue; }
        Serial.print((st >> 5) & 1); Serial.print(',');
        Serial.print((st >> 4) & 1); Serial.print(',');
        Serial.print((st >> 3) & 1); Serial.print('/');
        Serial.print(agc);           Serial.print('/');
        Serial.print(mag);
    }
    Serial.println();
    ok();
}

static void cmdNoise(const char* motorArg, const char* countArg) {
    int m = motorArg ? atoi(motorArg) : -1;
    int n = countArg ? atoi(countArg) : 50;
    if (m < 0 || m > 6) { err(5, "noise <motor 0-6> <n>"); return; }
    n = constrain(n, 2, 2000);
    int lo = 4096, hi = -1; long sum = 0; int bad = 0;
    for (int k = 0; k < n; ++k) {
        int v = MotorEncoders[m]->scanChecked();
        if (v < 0) { bad++; continue; }
        if (v < lo) lo = v;
        if (v > hi) hi = v;
        sum += v;
    }
    Serial.print(F("noise ")); Serial.print(kNames[m]);
    Serial.print(F(" n="));    Serial.print(n - bad);
    Serial.print(F(" bad="));  Serial.print(bad);
    Serial.print(F(" min="));  Serial.print(lo);
    Serial.print(F(" max="));  Serial.print(hi);
    Serial.print(F(" mean=")); Serial.print(bad < n ? (float)sum / (n - bad) : 0.0f, 1);
    Serial.println();
    ok();
}

// How far each rotor moves when torque is removed: read energised, drop
// torque, read again. Answers the half-step question directly (a ~9-10 count
// cluster is a rotor relaxing from a half-step to the nearest full-step
// detent) and shows what the de-energised check sees that the energised
// aligner did not.
static void cmdRelax() {
    if (cubeMotors.isHeld()) { err(6, "hold is on; relax needs to drop torque"); return; }
    int a[7], b[7];
    cubeMotors.enableMotors();
    delay(50);
    readAll(a);
    cubeMotors.disableMotors();
    delay(50);
    readAll(b);
    Serial.print(F("relax"));
    for (int i = 0; i < kMotors; ++i) {
        Serial.print(' '); Serial.print(kNames[i]); Serial.print('=');
        Serial.print(a[i]); Serial.print('/'); Serial.print(b[i]); Serial.print('/');
        if (a[i] < 0 || b[i] < 0) Serial.print('?'); else Serial.print(CubeSystem::encError(b[i], a[i]));
    }
    Serial.println();
    ok();
}

static void cmdHome() {
    Cube.clearAbort();
    unsigned long t0 = millis();
    int code = Cube.homeMotors();
    unsigned long dt = millis() - t0;
    Serial.print(F("home code=")); Serial.print(code);
    Serial.print(F(" ms="));       Serial.print(dt);
    Serial.print(F(" en="));       Serial.println(cubeMotors.isHeld() ? 1 : 0);
    int v[7]; readAll(v); printEnc(v);
    if (code) err(20 + code, "homing failed"); else ok();
}

// ----------------------------------------------------------------- moves --

struct RepStats {
    long  n[kMotors];
    long  sumRes[kMotors];
    long  sumSq[kMotors];
    int   maxAbs[kMotors];
    long  moves, notAligned, homings, failures;
    unsigned long moveMs;
};
static RepStats stats;

static void statsReset() { memset(&stats, 0, sizeof(stats)); }

// One physical move with the full record. Returns the move's result code:
// 0 ok, 2x homing failed (the firmware's own numbering), 3 bad token.
static int doMove(const char* tok) {
    if (!validToken(tok)) { err(3, "bad move token"); return 3; }
    Cube.clearAbort();

    int before[7], after[7];
    long pos0[kMotors], pos1[kMotors];
    readAll(before);
    for (int i = 0; i < kMotors; ++i) pos0[i] = cubeMotors.getPos(i);

    unsigned long t0 = micros();
    cubeMotors.executeMove(String(tok));        // physical move + settle
    unsigned long moveUs = micros() - t0;

    for (int i = 0; i < kMotors; ++i) pos1[i] = cubeMotors.getPos(i);
    readAll(after);

    // The firmware's own post-move contract (CubeSystem::executeMove): check
    // every motor against the nearest mark; if any is out, home once.
    bool aligned = Cube.checkAlignment();
    int  homed   = -1;
    if (alignMode && !aligned) homed = Cube.homeMotors();

    const float countsPerStep = 1024.0f / cubeMotors.getTurnStep();

    Serial.print(F("mv "));        Serial.print(tok);
    Serial.print(F(" code="));     Serial.print(homed > 0 ? 20 + homed : 0);
    Serial.print(F(" aligned="));  Serial.print(aligned ? 1 : 0);
    Serial.print(F(" homed="));    if (homed < 0) Serial.print('-'); else Serial.print(homed);
    Serial.print(F(" ms="));       Serial.print(moveUs / 1000.0f, 1);
    for (int i = 0; i < kMotors; ++i) {
        Serial.print(' '); Serial.print(kNames[i]); Serial.print('=');
        Serial.print(before[i]); Serial.print(','); Serial.print(after[i]); Serial.print(',');
        if (before[i] < 0 || after[i] < 0) {
            Serial.print(F("?,?,?"));
            continue;
        }
        // Where the commanded steps should have left the encoder. A "+" step
        // moves the reading DOWN when kAlignStepSign is +1: the aligner steps
        // + to correct a positive (reading above mark) error.
        long  dSteps   = pos1[i] - pos0[i];
        float expected = before[i] - CubeSystem::kAlignStepSign * dSteps * countsPerStep;
        int   expInt   = ((int)lroundf(expected)) & 0x0FFF;
        int   res      = CubeSystem::encError(after[i], expInt);
        int   e; int k = nearestMark(i, after[i], &e);
        Serial.print(res); Serial.print(','); Serial.print(k); Serial.print(','); Serial.print(e);

        if (dSteps != 0) {
            stats.n[i]++; stats.sumRes[i] += res; stats.sumSq[i] += (long)res * res;
            if (abs(res) > stats.maxAbs[i]) stats.maxAbs[i] = abs(res);
        }
    }
    Serial.println();

    stats.moves++;
    stats.moveMs += moveUs / 1000;
    if (!aligned) stats.notAligned++;
    if (homed == 0) stats.homings++;
    if (homed > 0)  stats.failures++;
    return homed > 0 ? 20 + homed : 0;
}

static void printRepSummary() {
    Serial.print(F("rep moves="));      Serial.print(stats.moves);
    Serial.print(F(" notaligned="));    Serial.print(stats.notAligned);
    Serial.print(F(" homings="));       Serial.print(stats.homings);
    Serial.print(F(" failures="));      Serial.print(stats.failures);
    Serial.print(F(" avgms="));         Serial.print(stats.moves ? (float)stats.moveMs / stats.moves : 0.0f, 1);
    Serial.println();
    // Per motor, over the moves in which that motor was commanded: mean and
    // RMS residual in counts, and the worst single move.
    Serial.print(F("res"));
    for (int i = 0; i < kMotors; ++i) {
        Serial.print(' '); Serial.print(kNames[i]); Serial.print('=');
        if (stats.n[i] == 0) { Serial.print(F("-")); continue; }
        float mean = (float)stats.sumRes[i] / stats.n[i];
        float rms  = sqrtf((float)stats.sumSq[i] / stats.n[i]);
        Serial.print(stats.n[i]); Serial.print(','); Serial.print(mean, 1); Serial.print(',');
        Serial.print(rms, 1);     Serial.print(','); Serial.print(stats.maxAbs[i]);
    }
    Serial.println();
}

// argv[0] is the count for rep; for seq it is the first token.
static void runSequence(char** argv, int argc, long reps) {
    if (argc < 1) { err(2, "no moves given"); return; }
    for (int k = 0; k < argc; ++k) if (!validToken(argv[k])) { err(3, "bad move token"); return; }
    while (Serial.available()) Serial.read();      // a stale byte must not stop run 1

    statsReset();
    for (long r = 0; r < reps; ++r) {
        for (int k = 0; k < argc; ++k) {
            if (Serial.available()) {
                Serial.println(F("# stopped by serial input"));
                printRepSummary();
                err(7, "stopped");
                return;
            }
            int code = doMove(argv[k]);
            if (code) {
                printRepSummary();
                err(code, "move failed");
                return;
            }
        }
    }
    printRepSummary();
    ok();
}

// ------------------------------------------------------------ mechanism --

static void cmdServo(const char* which, const char* what) {
    if (!which || !what) { err(2, "servo top|bot ext|ret|partial|eject"); return; }
    bool top = !strcmp(which, "top");
    if (!top && strcmp(which, "bot")) { err(2, "servo top|bot ..."); return; }
    if      (!strcmp(what, "ext"))     { if (top) Cube.topServoExtend();  else Cube.botServoExtend();  }
    else if (!strcmp(what, "ret"))     { if (top) Cube.topServoRetract(); else Cube.botServoRetract(); }
    else if (!strcmp(what, "partial")) { if (top) Cube.topServoPartial(); else Cube.botServoPartial(); }
    else if (!strcmp(what, "eject"))   { if (top) Cube.topServoEject();   else Cube.botServoEject();   }
    else { err(2, "servo ... ext|ret|partial|eject"); return; }
    cmdStatus();
}

static void cmdRing(const char* what) {
    if (!what) { err(2, "ring ext|ret|mid|partial"); return; }
    if      (!strcmp(what, "ext"))     Cube.ringExtend();
    else if (!strcmp(what, "ret"))     Cube.ringRetract();
    else if (!strcmp(what, "mid"))     Cube.ringMiddle();
    else if (!strcmp(what, "partial")) Cube.ringPartial();
    else { err(2, "ring ext|ret|mid|partial"); return; }
    cmdStatus();
}

static void cmdHelp() {
    Serial.println(F("# help status get set enc cal noise relax hold align load unload servo ring home move seq rep stop"));
    Serial.println(F("# see the header of Bench_Tune.ino for the record formats"));
    ok();
}

// ----------------------------------------------------------------- main --
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
void loop() {
    while (Serial.available()) {
        char ch = (char)Serial.read();
        if (ch == '\n' || ch == '\r') {
            if (lineLen > 0) {
                lineBuf[lineLen] = 0;
                lineLen = 0;
                dispatch(lineBuf);
            }
        } else if (lineLen < (int)sizeof(lineBuf) - 1) {
            lineBuf[lineLen++] = ch;
        } else {
            lineLen = 0;                // overlong line: drop it whole
            err(8, "line too long");
        }
    }
    pumpOnce();                         // keeps the abort chord alive between commands
}

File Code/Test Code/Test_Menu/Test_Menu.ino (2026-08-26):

// =============================================================================
//  Test_Menu — menu, navigation and panel test
// =============================================================================
//
//  A bench sketch for the wheel, the buttons and the themed panel. It drives
//  the SAME CubeMenu and CubeDisplay the real firmware does, so anything that
//  feels wrong here feels wrong there.
//
//  WHAT IT DOES
//  ------------
//  No scan, no solve, no calibration. What it does do is drive the actuators
//  directly, one at a time, from the Actuators menu — every servo position,
//  every ring position, every face motor in both directions, and both whole-
//  cube rotations. That is the panel version of Test Code/Actuator_Test, and it
//  is the reason this sketch is worth flashing to a real machine.
//
//  THESE MOVE REAL HARDWARE: the Actuators menu, Load/Eject, and Servo
//  Positions under Diagnostics > Tuning, which drives a horn to each value as
//  you dial it — that is the point of it. Everything else under Screens and
//  Diagnostics is drawing and navigation only.
//
//  Tuning previews on the wheel and COMMITS on the Apply row, which is the
//  last row of every section and the only thing here that writes an owner or
//  EEPROM. Walking away with edits pending asks, in red. Defaults live in the
//  shared kTune table (CubeTuneTable — one copy for this sketch and the
//  firmware); Diagnostics > Tuning > Reset Defaults puts every one of them
//  back.
//
//  THE TREE
//  --------
//    Load Cube / Eject Cube      real servos
//    Actuators                   real everything, one part at a time
//    Screens > Operations        scan, color capture, motor squaring, and
//                                the two endings — solve result, eject prompt
//            > Modes             the firmware's five Modes, same order
//            > Cube Views        the unfolded net, including the solve confirm
//                                and Cube State, where the wheel points at a
//                                face and UP/DOWN turn the MODEL — no motors
//            > Messages          info, error, stats
//            > Navigation        menu rendering at every item count
//    Diagnostics > Tuning        six sections, committed on Apply
//                > Input Report, Color Sensors, Motor Sensors, Fault Log
//                  Color Sensors is a two-board grid over a canned sweep;
//                  Motor Sensors lists eight rows and opens the same dial the
//                  calibration flow does — see DialOwner. Both are canned.
//
//  Screens > Modes deliberately mirrors the firmware's Modes menu item for item
//  and order for order. A rehearsal that groups the screens differently from
//  the machine stops being a rehearsal of the machine.
//
//  THE FRAME COLOR
//  ---------------
//  The band says WHERE YOU ARE, not what the machine is doing — see §2 of
//  docs/theme/UI_DESIGN.md. This sketch works the same way the firmware does:
//  s_opTheme is read off the selected row in loop(), and every operation screen
//  goes through opScreen(), which stamps it. Nothing calls showOperation()
//  directly.
//
//  Two places here are deliberately NOT wayfinding, and both earn it:
//  Screens > Navigation, whose five child screens are five different colors
//  because exercising all six IS the point of that subtree, and Screens'
//  children generally, which each wear the color of the FIRMWARE branch they
//  rehearse rather than their parent's — a screen photographed in the wrong
//  color is not a rehearsal of the screen the machine draws.
//
//  WHY THE SCREEN DEMOS ARE HERE
//  -----------------------------
//  The operation screens — scan step rows, calibration color chips, the solve
//  progress bar, the error look — are normally only reachable by running the
//  machine for real. On the bench that means a 40-second scan to check one
//  label. Screens > ... draws each of them from canned data, so the panel can
//  be judged in seconds and photographed without a cube in the chamber.
//
//  BOARD / SETUP
//  -------------
//  Teensy 4.1, same as the firmware. Set Arduino's sketchbook location to
//  Code/ so <CubeSystem.h> resolves. See the repo README.
//
//  Start-up takes ~10 s: CubeSystem::begin() sweeps both servos through the
//  real CubeServo code. It does NOT home the steppers.
//
//  CONTROLS (identical to the firmware — that is what is being tested)
//  -------------------------------------------------------------------
//    wheel / UP / DOWN     move the cursor
//    SELECT / RIGHT        enter a submenu, or run the item
//    LEFT                  back out one level
//    SELECT + LEFT         swallowed as the abort chord, never a menu action.
//                          Input Report is the one page where it is also the
//                          way OUT, because every other button is one the
//                          operator came there to press.
//
//  See docs/theme/UI_DESIGN.md before changing anything the panel draws.
// =============================================================================

#include <CubeSystem.h>
#include <CubeHardwareConfig.h>
#include <CubeMenu.h>
#include <CubeTuneTable.h>   // the shared tuning table; the editor UI is here

CubeSystem Cube;
CubeMenu   Menu;

using Op = CubeDisplay::OpKind;

// ---------------------------------------------------------------------------
//  State
// ---------------------------------------------------------------------------
//  Deliberately smaller than the firmware's AppState. There are no long
//  operations to model here: a mechanical move runs to completion inside one
//  loop() pass, and everything else is either the menu or a screen waiting to
//  be dismissed.
enum class TState : uint8_t {
    Menu,       // CubeMenu has the panel
    Screen,     // a full-screen view; SELECT or LEFT returns
    Jog,        // direct actuator control; see the note above pollJog()
    Params,     // a settings list; the wheel changes a value, not a cursor
    ParamsLeave,// the red confirm before walking away from unapplied edits
    MotorDial,  // one face motor on the wheel; see calDialLoop(). Named for the
                // SCREEN rather than for the calibration flow, because two
                // pages open it now — see DialOwner.
    CubeState,  // the stored model, with the wheel on a face; see csTurn()
    Loading,    // clamp the cube, once
    Ejecting    // release and present it, once
};

static TState state = TState::Menu;
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

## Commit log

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2023-10-21 New Top Bracket
    Updated top servo extended position and reduced steppers speed.
2023-10-23 Implemented Virtual Cube Rotation Functions
    Note: rebuild from cube array not functional as intended, does not currently rebuild cube just rewrites colorCubeArray
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2023-10-25 Started String Parsing File
    Really weird errors though
    [StringParsingTest.ino]
2023-10-26 Fixed virtual cube library
    [ScrambleSolve.ino]
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2025-05-15 Servo Position Initialization
    Servos will now reset with a sweep if necessary.
    [Test_Motor_Calibrate.ino]
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2025-05-21 Scan Cube Tested (Sensors not working?)
    [Actuator_Test.ino, Test_Color_Calibrate.ino, Test_Scan_Solve.ino]
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2025-08-05 Replaced MotorPots with MotorEncoders
    To Do:
    Test Motor Encoder code to verify if it works
    Update color sensor code for new color sensor boards
    Update all pins for new motherboard
2025-09-15 Added SolidWorks and KiCad files to repo
    [2717.step, 4x6 Board Holder.SLDPRT, 4x6 Board Holder.STL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]
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2025-09-17 Motors confirmed working
    [Motor Breakout.kicad_pcb]
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2025-10-11 New version of bottom motor assembly mostly designed
    [Bottom Motor Assembly.SLDASM, Bottom Motor Bracket 6-10-24.STL, Bottom Motor Bracket.SLDPRT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]
2025-10-12 Color Sensor Designed
    [Bottom Motor Assembly.SLDASM, Bottom Motor Bracket.SLDPRT, Bottom Motor Track Stand New.SLDPRT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]
2025-10-14 Color Sensor and Bottom Motor Assembly Full Design
    [Bottom Motor Assembly.SLDASM, Bottom Motor Track.3mf, Bottom Motor Track.SLDPRT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]
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2025-10-21 Color calibration potentially working!
    [Bottom Motor Assembly.SLDASM, Color Sensor Subassembly.SLDASM]
2025-10-22 Bottom Motor CAD Finalized
    [Bottom Motor Assembly.SLDASM, Bottom Motor Track Stand New.SLDPRT, Bottom Motor Track Stand.SLDPRT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]
2025-10-24 Reduced color sensor body height to reduce obstruction
    [Bottom Motor Assembly.SLDASM, Color Sensor Subassembly.SLDASM, Ring Motor Assembly.SLDASM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]
2025-10-28 Cube Holders, Color Scan Debugging
    [Cube Holder.SLDPRT]
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2025-11-03 Initial Top Servo Track Redesign
    [Bottom Motor Assembly.SLDASM, Ring Motor Assembly.SLDASM, Servo Assembly.SLDASM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]
2025-11-04 Top Frame Print
    [Top Motor Holder Frame Remodel.STL, Top Motor Holder Frame.3mf]
2025-11-11 Top Motor Assembly Printed
    [4x6 Board Holder.SLDPRT, 4x6 Board Holder.STL, 7x9 Board Holder.SLDPRT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]
2025-11-13 Top Motor Assembly Revision
    [Top Motor Bracket.SLDPRT, Top Motor Bracket.STL, Top Motor Track Cap.SLDPRT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]
2025-11-18 Top Servo Installed and Working
    [Side Motor Assembly.SLDASM, Top Motor Assembly Print.3mf, Top Motor Assembly.SLDASM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]
2025-11-19 Solve with Button and Screen Working!
    [5221 ANO Rotary Encoder.step, Barrel Jack.SLDPRT, Barrel Jack.stp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]
2025-11-22 Display Bracket Prototyped
    [2.2 TFT LCD Display Modul 240x320.SLDPRT, 5221 ANO Rotary Encoder.SLDPRT, 5221 ANO Rotary Encoder.step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]
2025-11-25 Forward Alignment Testing
    [Display Panel Assembly.SLDASM, Display Panel.SLDPRT, Side Motor Assembly.SLDASM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]
2025-12-01 Display Panel Designed
    [Display Panel Assembly.SLDASM, Display Panel Mount.SLDPRT, Display Panel Mount.STL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]
2025-12-01 Integrated Cube Display
    [Display Panel Assembly.SLDASM]
2026-08-13 Repo hygiene: ignore generated files, commit lv_conf.h
    Untrack 198 regenerable files that were bloating history: 159 KiCad
    *-backups/ zips, 20 .kicad_prl, 9 fp-info-cache (3.3 MB each), 6
    SolidWorks ~$ locks, 3 editor .lck, 1 _autosave-. Verified every one is
    tool output; nothing under Code/ is affected. Files stay on disk — this
    is `git rm --cached` only, no history rewrite.
    Add lv_conf.h at Code/libraries/. LVGL will not compile without it and
    its settings are not defaults, so the project could not previously be
    rebuilt from a clean checkout by anyone. Annotated: which settings are
    load-bearing (LV_COLOR_DEPTH must match ILI9341_T4 or you get wrong
    colours that look like a hardware faul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
2026-08-13 Add README
    The project had no prose documentation beyond a note in _Archive saying
    its contents were superseded. The dependency list, the sketchbook layout
    that makes the includes resolve, the board, and which of the eighteen
    sketches is actually the firmware all existed only in the author's head —
    and the commit history shows two returns to this project after 6-9 month
    gaps.
    Contents: what to flash, build setup including the non-obvious sketchbook
    step, the full dependency table, the pin map and I2C addresses verified
    against the KiCad board file, the operating procedure, and the error code
    table.
    Two things worth calling out:
    - The firmware puts the scroll wheel on Wire1 (pins 16/17) b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
2026-08-13 Menu system: data-driven menu tree, list rendering, SELECT+LEFT abort
    Replaces the flat five-item menu in CubeSolver.ino with a nested menu tree
    and the display support it needs. Screen structure is now data; the sketch's
    `switch (menuIndex)` could not have grown submenus without one index space
    and one bounds check per screen, all in the same statement.
    MENU ENGINE (new: CubeMenu.h/.cpp)
    - A screen is a table of items; an item opens a submenu or fires an action.
    - Depends on nothing but <stdint.h>. Rendering leaves through a callback and
    input arrives as a MenuEvent, so the navigation logic compiles and runs on
    a host. Code/tests/test_menu.cpp exercises it with 62 assertions: wrap,
    c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
2026-08-13 Desktop simulator: run the menu on a PC without the machine
    Builds the real firmware against SDL-backed hardware shims, so menu layout
    can be tuned without a Teensy on the bench.
    WHAT IS REAL
    The sketch, CubeMenu, CubeDisplay, RotaryEncoder, CubePump, CubeServo,
    CubeMotors, ColorSensor, MotorEncoder and VirtualCube are compiled
    unmodified — ino_main.cpp is literally `#include "CubeSolver.ino"`.
    CubeSystemSim.cpp is the ONLY firmware file the simulator replaces. There
    is no second copy of the menu to drift out of step with the firmware.
    LVGL v9.1 is fetched by CMake, pinned by commit, and uses the firmware's own
    lv_conf.h — including its 32 KB LV_MEM_SIZE, so pool pressure and font
    metr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
    [Arduino.cpp, CubeSystemSim.cpp]
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2026-08-17 Test_Menu: bench sketch for the menu, wheel and panel
    A test sketch for the navigation hardware and the themed panel. It drives the
    SAME CubeMenu and CubeDisplay the firmware does — the input polling is copied
    from CubeSolver.ino verbatim rather than approximated, because that polling is
    the thing under test — so anything that feels wrong here feels wrong there.
    NO FUNCTIONALITY EXCEPT LOAD AND EJECT
    No scan, no solve, no calibration, and no stepper motion of any kind. The only
    things that move are the two servos and the ring, and only when Load or Eject
    is picked. Both use the firmware's own ordering (bottom, ring, top for a load),
    which is mechanically load-bearing and worth exercisin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
    [Test_Menu.ino]
2026-08-17 Scan progress as face chips, and a plan for the unbuilt screens
    THE SCAN SCREEN WAS SAYING THE WRONG THING
    It showed the three scan passes as menu bars — glowing, socketed, cursor and
    all. That art is this theme's vocabulary for "you can select this", so a screen
    full of it promised an interaction that was not there, and read as a row of
    buttons that did nothing.
    Replaced with a row of six face chips: one per cube face, labelled U R F D L B,
    hollow until read and then filled with the colour that face's centre sticker
    ACTUALLY came back as. scanCube() already had those letters — it reads
    r1[4].color and r2[4].color to identify each face — so the row costs nothing to
    produce and turns a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
    [CubeSystemSim.cpp, Test_Menu.ino]
2026-08-17 Document why the scan order changed, and why it was free
    The scan order comment was stale because the colour scanner was rotated 90
    degrees in CAD to make the assembly fit. That changed which faces each pass
    reads and needed no firmware change at all, so nothing prompted the comment to
    be updated and it quietly went wrong.
    Records the reason rather than just the corrected order, because the reason is
    the useful part: scanCube() identifies each face from its own centre colour and
    its neighbour's, never from an assumed position, so WHICH faces a pass sees is
    free to change. What the design does depend on is the two sensors' geometry
    RELATIVE TO EACH OTHER — sensor 2 to the left of sensor 1,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
2026-08-17 Cube net, and Cube State built on it
    First of the shared pieces from SCREEN_PLAN.md, and the one three screens were
    waiting on.
    THE NET
    setOpCubeNet() takes 54 colour letters in the standard facelet order and draws
    the unfolded cross. VirtualCube::getColorArray() returns exactly that — a new
    accessor, because getCubeArray() has already translated colours into U/R/F/D/L/B
    (through the 'B' -> 'P' placeholder dance in buildCubeArray) and can no longer
    say what colour anything is.
    It is neither LVGL primitives nor lv_canvas. It writes RGB565A8 into a plain
    static buffer and hands that to an lv_image:
    - 54 stickers as objects would be most of the LVGL pool for one screen.
    - The buffer is 39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
    [CubeSystemSim.cpp]
2026-08-17 Colour calibration: show the required cube orientation before starting
    calibrateColorSensors() never identifies what it is looking at. It ASSERTS that
    rotation 1 is showing it Red and Green, rotation 2 Blue and Red, and so on, and
    files whatever the sensors return under the colour it expected. A cube loaded
    turned the wrong way therefore teaches it wrong colours and writes them to
    EEPROM, with nothing anywhere to notice — and every scan afterwards misreads.
    So the orientation is not advice, it is part of the procedure, and the machine
    now says what it is: a prompt screen showing the required solved cube as a net,
    with the faces named underneath, waiting on SELECT. LEFT backs out.
    The ori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
2026-08-17 Correct the calibration orientation for the rotated colour scanner
    The colour scanner was turned 90 degrees in CAD, so the sensors now read Back
    and Right where they used to read Left and Back. The previous commit's required
    orientation was derived from the stale positions and was wrong.
    WHAT ACTUALLY NEEDED FIXING, AND WHAT DID NOT
    The faceColors/topFaces tables are COLOUR labels, not positions. Nothing in
    calibrateColorSensors() names a face except in its comments — it files whatever
    sensor 1 returns under the first colour and sensor 2's under the second. So the
    scanner rotation did NOT require the tables to change. It required the cube to
    be loaded 90 degrees round to match, and that i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
2026-08-17 Label the cube net with face letters
    The net alone relied on the reader knowing the unfolded-cross convention. The
    machine has U R F D L B written on it, so putting the same letters on the
    picture turns an inferred instruction into a literal one — which matters most
    on the calibration prompt, where reading it wrong writes a bad calibration to
    EEPROM.
    Each letter sits on its face's centre sticker and picks its ink from that
    sticker's brightness rather than from a per-colour table, so white and yellow
    get dark letters and the rest get light ones without anything needing revisiting
    when the palette moves. A face drawn hollow because its colour was not read
    falls out of the same rule.
    On by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
2026-08-17 Test_Menu becomes the workbench; prototype the Scramble Solve screen there
    New screens get built in the bench sketch first, not in the firmware. It needs
    no cube, no machine and no solver, it runs in the simulator, and it keeps
    half-finished UI out of the sketch that drives real motors. Written into
    CLAUDE.md and SCREEN_PLAN.md so it is the default rather than this session's
    habit.
    CATCHING THE BENCH SKETCH UP
    It had drifted behind the firmware — the cube net, the newest primitive, was the
    one thing it could not show, which is backwards for the sketch that exists to
    judge panel work. It now demos the net three ways: a solved cube, a checkerboard
    and the orientation colour calibration requ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
    [Test_Menu.ino]
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2026-08-17 Hardware Test, and row status marks to build it on
    Next in the plan. setOpLines() takes an optional RowMark per row — Plain, Good,
    Bad, Busy — and tints the value half accordingly, from the theme's own palette:
    its green edge, its red edge, the cursor yellow. A checklist you watch running
    should be readable by colour before it is readable by word.
    The screen is a checklist that ticks itself off, prototyped in Test_Menu under
    Screens > Operations. No progress bar: the rows ARE the progress, and a second
    indicator saying the same thing would only compete with them. The frame goes red
    at the end if anything failed, so the verdict reads from across the room. One
    part fails on purpose — a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
    [Test_Menu.ino]
2026-08-17 Hardware Test is manual actuator control, not a self-test
    I built the wrong thing. The previous commit made Hardware Test an automated
    checklist that ticks itself off. It is not that: it is direct manual control,
    the panel version of Test Code/Actuator_Test's numbered Serial menu — drive each
    part to each position by hand, to answer "does that servo actually reach
    retract", and to show the machine off one actuator at a time.
    So it is a MENU, and bars are correct throughout. Grouped by part rather than
    flattened, because five items is the screen limit and there are six face motors.
    Opposite faces share a screen, which is a grouping that means something rather
    than an arbitrary split: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
    [CubeSystemSim.cpp, Test_Menu.ino]
2026-08-17 Actuators: two jog pages instead of a menu tree
    The submenu tree was clunky, and the reason is that a menu is the wrong shape
    for this. Driving the grippers through their positions was nine entries across
    three screens; the faces were twelve more. All of it clicked one item at a time,
    when what you want is to pick a thing and nudge it while you watch it move.
    The two busy pages are now direct manipulation. They can be, because the wheel
    and the UP/DOWN BUTTONS are separate inputs on this encoder — the menu collapses
    them into one meaning, and a jog page gives them two:
    wheel choose which part
    UP / DOWN move that part
    LEFT back, exactly as everywhere else
    Gr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
    [Test_Menu.ino]
2026-08-17 Actuators: everything on one page
    Eleven things on one wheel — three grippers, six face motors, two whole-cube
    rotations — with no submenu at all. The wheel wraps, so nothing is more than
    five or six detents away.
    There is a reason beyond tidiness. A face motor cannot turn until the grippers
    are clear, so being able to see where the grippers ARE while jogging a face is
    the difference between a considered press and a jam. Splitting them across two
    pages hid exactly the thing you need to check before pressing.
    The grippers stay a status table with the cursor as a marked row. Everything
    that turns is one chip strip, faces and whole-cube rotations together, because
    they are the same gestur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
    [Test_Menu.ino]
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2026-08-17 Actuators: take the wheel to turn a motor, one cube button, fix the cursor
    THE CURSOR SKIPPED ROWS WITH NO VALUE
    setOpLines() applied a RowMark to the value half only, so "Load cube" and "Eject
    cube" — which have nothing in that column — stayed grey while every other row
    lit up. The mark now falls back to the label when there is no value, which is
    what a cursor has to do to be a cursor.
    TAKE THE WHEEL
    Entering a motor now hands it the wheel: every detent is a turn. Watching a
    motor through several turns costs no button presses at all, which is the point
    of a jog wheel and was not true when each turn was its own button press.
    That makes the interaction one rule everywhere — scroll to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
    [Test_Menu.ino]
2026-08-17 Move ribbon, and Step Solve built on it
    Next in the plan. setOpRibbon(moves, count, current) draws a window of a move
    sequence with a cursor on the one being run: past dimmed, current in cursor
    yellow, future plain.
    Plain text with no boxes, deliberately. Boxed tokens would drift back toward
    looking like buttons — the mistake the scan screen made — and colour alone
    carries the cursor perfectly well.
    Two details that only show up once it moves: the slots are FIXED WIDTH, so
    tokens do not shuffle sideways as the cursor advances and the row stays still;
    and the window clamps at both ends rather than always centring, or the last few
    moves would drift off one side trailing blank slots behin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
    [Test_Menu.ino]
2026-08-17 Tidy the screen plan's status sections
    Both had been struck through and renumbered in place enough times that the
    ordered list ran 1, 2, 4, 5 with finished items interleaved between the
    unfinished ones. Rewritten rather than patched again.
    Now says plainly what is built (with the call that provides it), what has a
    screen but no machine behind it yet, and what is genuinely still to do. Notes
    that the value editor is mostly solved already — the Actuators page's
    enter-pick-send on a gripper IS that interaction, and what is left is a number
    rather than three named positions.
    Claude-Session: https://claude.ai/code/session_01WC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
2026-08-17 Sensor Test, and raise LV_MEM_SIZE to 64 KB
    Two health rows and eighteen live colour chips, nine per board. The chips ARE
    the readout: eighteen colour names would take longer to read than the cube takes
    to scan, and the thing you are hunting — one sensor disagreeing with its
    neighbours — shows up instantly as a chip of the wrong colour.
    The demo draws board 2 sensor 2 as a known-bad sensor, because on this machine
    it is one: a dead green channel, already documented in the README. A diagnostic
    that only ever shows healthy hardware is not a diagnostic.
    setOpChipRow() takes a row index now, since this is the first screen wanting two
    rows of chips that are not the calibration's. Captions b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
    [Test_Menu.ino]
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2026-08-17 Test_Menu: Fault Log screen; document simulator focus drift
    The Fault Log is the last of the Diagnostics screens. It shows a scrolling
    window over the stored faults, seven rows at a time, with the position in the
    hint bar ("1-7 of 14") rather than inventing scrollbar art the theme has no
    vocabulary for.
    Scrolling clamps at both ends instead of wrapping. A menu that wraps is fine
    because every item is equivalent, but a log has a real top and a real bottom,
    and wrapping past the oldest entry into the newest would misrepresent when
    things happened.
    Codes are drawn as faults except code 70, which is the user aborting. Marking a
    deliberate stop in the same red as an encoder failure would train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
    [Test_Menu.ino]
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2026-08-17 Tuning: six sections, defaults in source, overrides in EEPROM
    Replaces the two ad-hoc parameter screens with the set actually worth changing,
    grouped the way the machine is: top servo, bottom servo, ring, face motors,
    alignment, color. Every row carries a one-line description in the sub-line, so
    what a value does is on screen next to the value.
    Persistence via CubeTuning: a version stamp plus a flat int32 array. Values are
    stored by position, so reordering the table must bump kVersion - otherwise the
    next boot hands an alignment tolerance to a servo. The block is appended at the
    END of the EEPROM layout and has to stay there, because addresses are handed out
    sequentially and a block inserte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
    [CubeSystemSim.cpp, Test_Menu.ino]
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2026-08-18 Test_Menu: Step Solve scrambles first; Idle Mode turns the cube
    Step Solve now scrambles thirty moves before stepping, unless the cube is
    already scrambled. Tracking that is the point rather than a detail: Idle Mode
    disorders the cube as a side effect of running, and a previous step solve leaves
    it solved, so "scramble first" and "do not scramble" are both wrong as
    unconditional rules. Three phases - red scrambling, yellow computing, green
    stepping - and the compute phase clears the ribbon and progress bar, which left
    up would put a finished ribbon and a full bar under the word "Solving".
    Idle Mode is rebuilt around what it should actually do: a random quarter turn
    every so often, a count o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
    [Test_Menu.ino]
2026-08-18 CubeSolver 1.0.0: every menu item is a real screen
    The firmware now carries everything the test sketches proved out. The five
    Modes (Scramble Solve, Idle, Demo, Step Solve, Patterns) run one verified
    move per loop() pass on the existing executeMove/solveVirtual API, so the
    panel and the abort chord stay live at every move boundary. The Hardware
    Test jog page, Sensor Test and the value editor are ported from Test_Menu;
    the 28-row tuning table moves to a shared CubeTuneTable so the bench sketch
    and the firmware cannot drift on the EEPROM layout. Two new
    CubeTuning-shaped blocks append after tuning: a 24-entry fault ring (2349)
    and lifetime stats counters (2547) - 2600 of 4284 bytes used.
    Solv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
    [CubeSystemSim.cpp, Test_Button_Wheel_Lib.ino, Test_Button_with_Screen_Lib.ino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]
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2026-08-23 Motion bench tooling, ramp/hold support, calibration readouts; plus pending UI work
    Motion reliability (22 Aug 2026 bench sessions):
    - CubeMotors: tunable acceleration ramp (setStepAccel; 0 keeps the constant-speed
    move), hold-torque latch (holdBegin/holdEnd makes disableMotors a no-op across a
    move train), optional enable dwell. All default to previous behaviour.
    - MotorEncoder::readHealth: AS5600 STATUS/AGC/MAGNITUDE, the first read of the
    magnet registers anywhere in the tree.
    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
    [session1.csv, session2-U.csv, session3-others.csv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]
2026-08-26 Five more patterns, a Stats reset, and full turns on the diagnostic dial
    - Patterns grows a More Patterns screen: Cube^3, Anaconda, Python, Tetris
    and Twister join the original four. One shared fold body; each screen's
    rows index the kPattern* tables from its own base.
    - Stats: Best and Average now speak only for solves longer than
    kStatMinMoves (a lucky three-move draw is not a record), Best carries its
    move count, and SELECT+RIGHT held five seconds resets the block with a
    countdown. The page owns its input so the chord can be seen at all.
    - The diagnostic motor dial's UP/DOWN run real aligned quarter turns (plain
    and prime) for chasing direction-dependent encoder faults; the Ca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
    [Bench_Tune.ino, Test_Menu.ino]
2026-08-26 3D models: storage wall and calibration cube, plus resaved parts
    Two new prints — a Storage Wall and a Calibration Cube STL — and a sweep of
    resaved SolidWorks parts and assemblies across the tree.
    Claude-Session: https://claude.ai/code/session_01DoUR44DVdiaqFYoN1S1R36
    [2.2 TFT LCD Display Modul 240x320.SLDPRT, 5221 ANO Rotary Encoder.SLDPRT, AS5600.SLDPRT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]
2026-08-27 Panel watchdog for the scroll white-out, Stats no longer self-exits, dial keeps torque
    The white screen after a menu scroll was the panel latching a corrupted
    command (RAMWR/CASET are one bit from DISPOFF) during the full-frame band
    recolor a detent forces, with nothing ever re-initializing the controller.
    CubeDisplay::panelHealthTick() now re-sends DISPON+SLPOUT every second and
    re-runs the full bring-up when the self-diagnostic register reads wrong, so
    a white-out heals in about a second. Also: Stats swallows the release of
    the click that opened it, and the diagnostic dial re-energizes the drivers
    after executeMove() de-energizes them.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
